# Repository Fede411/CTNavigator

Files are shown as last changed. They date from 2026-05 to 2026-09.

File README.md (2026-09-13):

# CTNavigator

An open-source surgical navigation prototype for orthopaedic oncological surgery, built entirely from low-cost consumer hardware and an open software stack. It localizes a surgical instrument with a stereo pair of Microsoft Kinect v1 sensors and displays it in real time within the patient's CT inside [3D Slicer](https://www.slicer.org/).

This repository contains the code and STL files developed for the Master's Thesis *"Design, Development and Validation of an Open-Source Orthopaedic Oncological Surgical Navigator"* (Universidad Politécnica de Madrid, ETSIT).

> **Status — research prototype.** This system is a proof of concept. Its accuracy (target registration error of ≈9.5 mm) is **not** sufficient for clinical use, and it carries no medical-device certification. It is intended as a reproducible research and development platform, not for use on patients.

---

## How it works

The system has two components that communicate over the [OpenIGTLink](http://openigtlink.org/) protocol:

1. **Tracking backend (C#)** — acquires infrared frames from two Kinect v1 cameras, detects the retroreflective spheres, reconstructs their 3D positions by stereo triangulation, estimates the pose of the tracked instrument and reference marker, and streams the resulting transforms.
2. **Navigation module (Python / 3D Slicer)** — receives those transforms, registers physical space to the CT via paired fiducials, and renders the instrument in real time inside the patient's anatomy.

```
Kinect A ─┐
          ├─► C# tracking backend ──(OpenIGTLink TRANSFORM)──► 3D Slicer module ──► navigation view
Kinect B ─┘
```

---

## Requirements

### Hardware
- **2× Microsoft Kinect v1 (Model 1414)**, mounted as a stereo rig (a 3D-printable casing is provided).
- Each Kinect on its **own USB controller** (two Kinect v1 units saturate a single controller's bandwidth).
- A retroreflective-marker instrument and a reference marker (STL files provided in [`/models`](models)).

### Software
- **Windows** (the Kinect v1 SDK is Windows-only).
- **Kinect for Windows SDK v1.8**.
- **.NET Framework** (matching the backend build).
- **3D Slicer 5.x** with the **SlicerIGT** and **SlicerOpenIGTLink** extensions installed.
- *(Optional, for calibration)* MATLAB with the Stereo Camera Calibrator app, or OpenCV.

---

## Installation

### 1. Tracking backend
A precompiled executable is provided in `/backend`. On first run it creates two folders next to the executable — `output/` (characterization and mapping CSVs) and `calib/` (calibration captures) — so no path configuration is required.

### 2. 3D Slicer module
The navigation module is a Python scripted module (`CTNavigator.py`, `CTNavigator.ui`).

1. In 3D Slicer, go to **Edit → Application Settings → Modules**.
2. Under **Additional module paths**, add the folder containing `CTNavigator.py`.
3. Restart Slicer. The module will appear under the **CTNavigator** category.

The module launches the tracking backend (`KinectTracker.exe`) automatically; keep it in the same folder as `CTNavigator.py`. To use a different location, set the `CTNAVIGATOR_EXE` environment variable to its full path.

---

## Calibration

Example calibration parameters are included so the system runs out of the box, **but calibrating your own rig is practically obligatory** — the extrinsics depend on the exact physical placement of your two cameras.

Two independent routes are supported:
- **MATLAB Stereo Camera Calibrator** (reference).
- **Two-stage OpenCV pipeline** (fully open-source alternative): each camera is calibrated individually over its full field of view, then the stereo extrinsics are solved with the intrinsics held fixed.

Place the resulting parameters in the calibration folder used by the backend (see the absolute-path note above). A 3D-printable checkerboard pattern is provided in [`/models`](models).

---

## Usage

1. Connect and power both Kinects (each on its own USB controller).
2. Run the tracking backend; confirm both cameras stream infrared and the markers are detected.
3. In 3D Slicer, open the **CTNavigator** module and load the patient CT (and segmented model, if available).
4. Open the OpenIGTLink connection to the backend; the connection status is shown in the module.
5. **Register**: click each anatomical landmark on the CT, then capture the same points physically with the instrument tip (one capture per landmark, same order). The fiducial registration error is displayed and colour-coded as feedback.
6. Navigate: the instrument now appears in real time within the patient's imaging. A dedicated navigation window can be opened for the clinical view.

---

## Repository structure

| Path | Contents |
|---|---|
| `SlicerModule/` | 3D Slicer Python module (`CTNavigator.py`, `CTNavigator.ui`, `Resources/`) and a copy of the tracking backend (`KinectTracker.exe`) |
| `KinectTracker/Kinect-PLUS/` | C# tracking backend source (`.cs`, `.csproj`, `packages.config`) |
| `Hardware/KinectCase/` | STL files for the stereo-camera casing and mounts |
| `Hardware/Calibration/` | Example checkerboard STL used for calibration |

> The `KinectTracker.exe` shipped alongside the module is the compiled backend; the C# sources under `KinectTracker/Kinect-PLUS/` build the same executable. NuGet packages (Emgu.CV, MathNet, etc.) are restored automatically on build.

---

## Known limitations

- **Not for clinical use.** Target registration error ≈9.5 mm, far above what orthopaedic oncological resection requires, and with no CE marking or regulatory approval.
- **Discontinued hardware.** The Kinect v1 is end-of-life and no longer manufactured; long-term reproducibility would benefit from migrating to a currently supported depth camera (e.g. Intel RealSense D455). The tracking pipeline is not tied to the Kinect — it only requires a calibrated stereo pair of infrared cameras.
- **Working volume and pose availability** depend on position and orientation; tracking degrades in peripheral and oblique regions.

---

## Citation

If you use this work, please cite the accompanying Master's Thesis:

> F. Sangineto Cotrina, *Design, Development and Validation of an Open-Source Orthopaedic Oncological Surgical Navigator*, Master's Thesis, Universidad Politécnica de Madrid (ETSIT), 2026.

---

## License

This project is released under the [BSD 3-Clause License](LICENSE). You are free to use, modify and redistribute it, including commercially, provided the copyright notice and disclaimer are retained and the authors' names are not used to endorse derived products without permission.

---

## Acknowledgements

Developed within the collaboration between the UPAM3D unit of *Hospital General Universitario Gregorio Marañón* and the Bioengineering and Telemedicine Group (GBT-UPM). Built on the open-source ecosystem of 3D Slicer, SlicerIGT and OpenIGTLink.

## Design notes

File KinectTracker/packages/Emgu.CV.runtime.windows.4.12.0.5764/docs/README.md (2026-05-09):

## About this package

This package is part of the 4.12.0 release of Emgu CV. 

For online documentation please visit
<https://www.emgu.com/wiki/files/4.12.0/document/index.html>

Release note can be found at
<https://www.emgu.com/wiki/index.php/Version_History#Emgu.CV-4.12.0>

## Note

If you are targeting .Net Framework, please read this first:
<https://www.emgu.com/wiki/index.php/Download_And_Installation#Targeting_.Net_Framework>

If you have issues getting the pacakge installed for your project, and your project use packages.config to manage nuget packages, the following instructions will help:
<https://www.emgu.com/wiki/index.php/Download_And_Installation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>

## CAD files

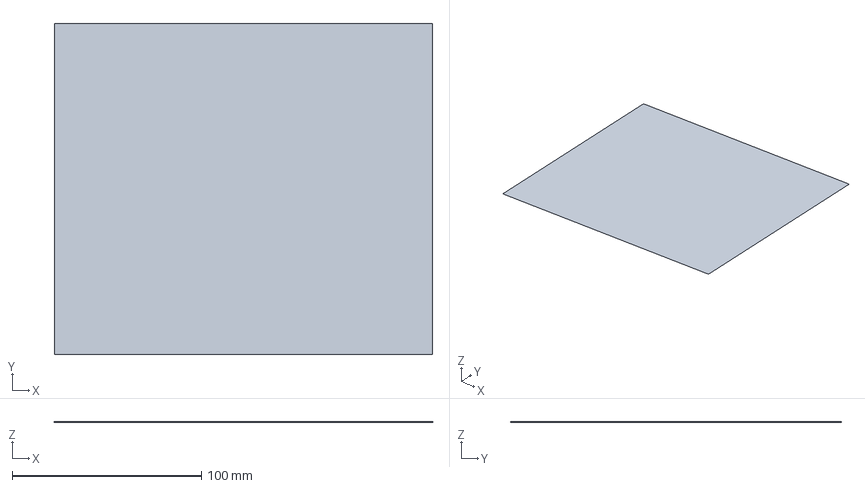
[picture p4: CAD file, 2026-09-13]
Hardware/Calibration/checkerboard_25mm_8x7.3mf
200.0 x 175.0 x 0.22 mm

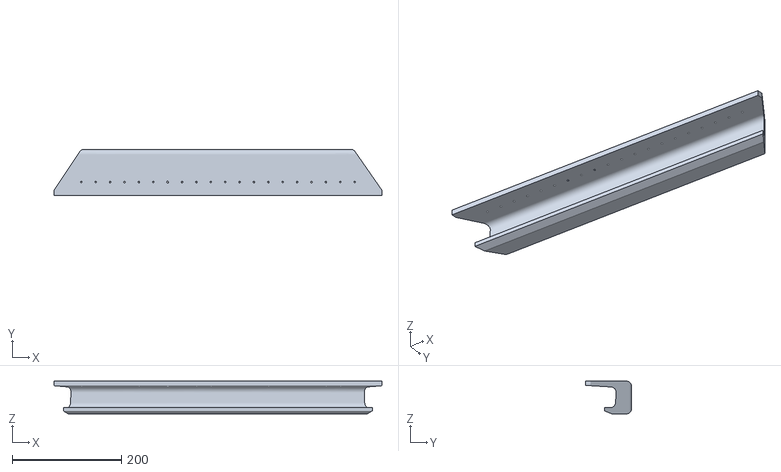
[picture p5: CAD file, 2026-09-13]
Hardware/KinectCase/KinectCase_M3.5.stl
600.0 x 85.0 x 60.0

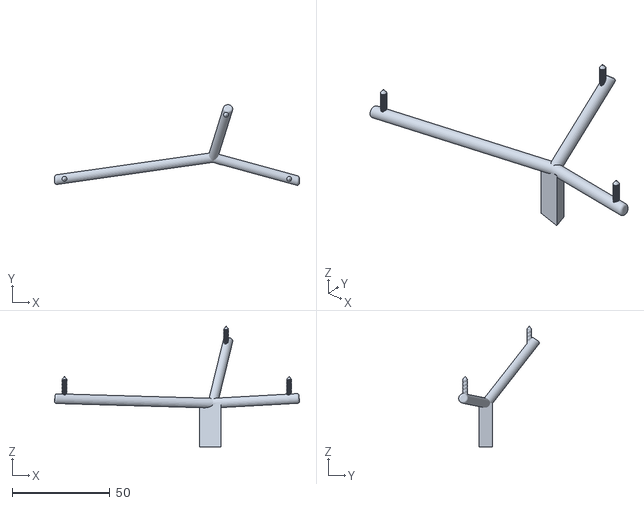
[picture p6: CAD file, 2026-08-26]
Hardware/marcadorV2.stl
125.4 x 41.3 x 61.9

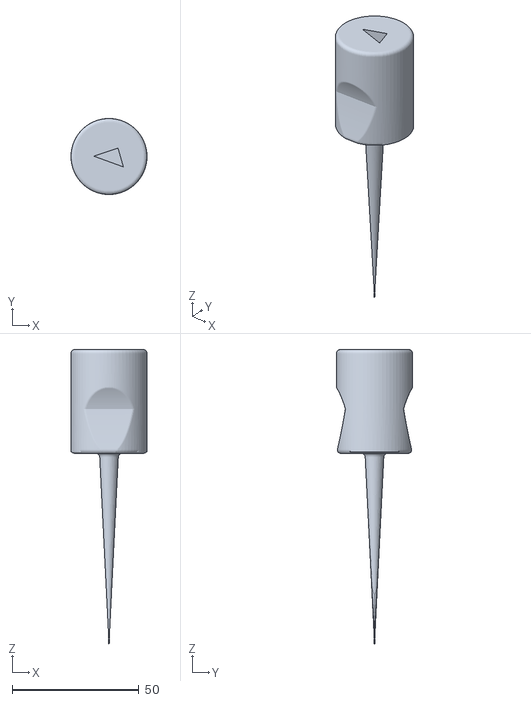
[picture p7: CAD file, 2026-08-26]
Hardware/instrumento3.stl
30.0 x 30.0 x 116.0

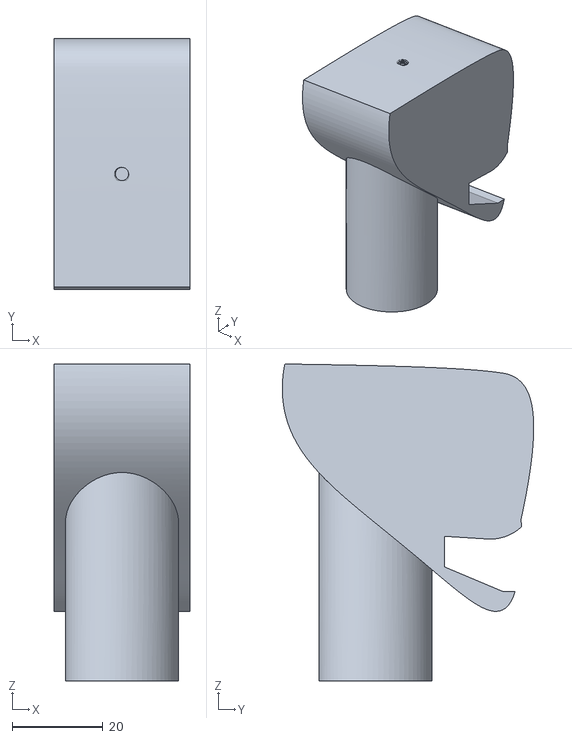
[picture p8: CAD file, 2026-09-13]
Hardware/KinectCase/adaptador_tripod_kinect_M6.stl
30.0 x 55.5 x 70.0

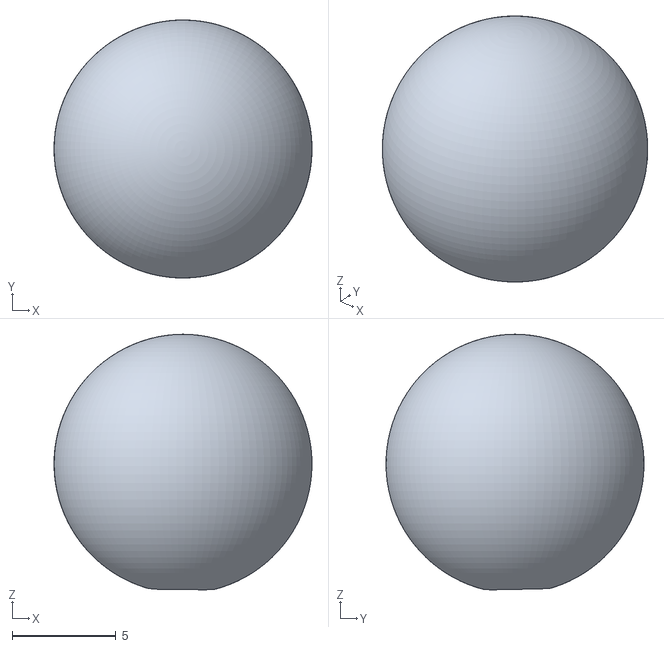
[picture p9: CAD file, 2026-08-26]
Hardware/BolaIR.stl
12.4 x 12.4 x 12.3

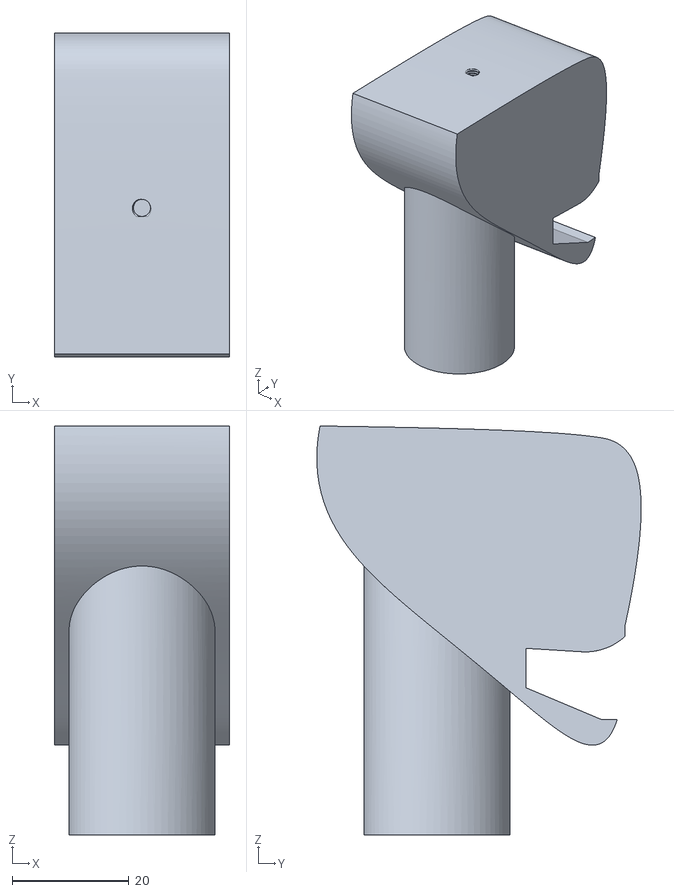
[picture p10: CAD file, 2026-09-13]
Hardware/KinectCase/adaptador_tripod_kinect_M8.stl
30.0 x 55.5 x 70.0

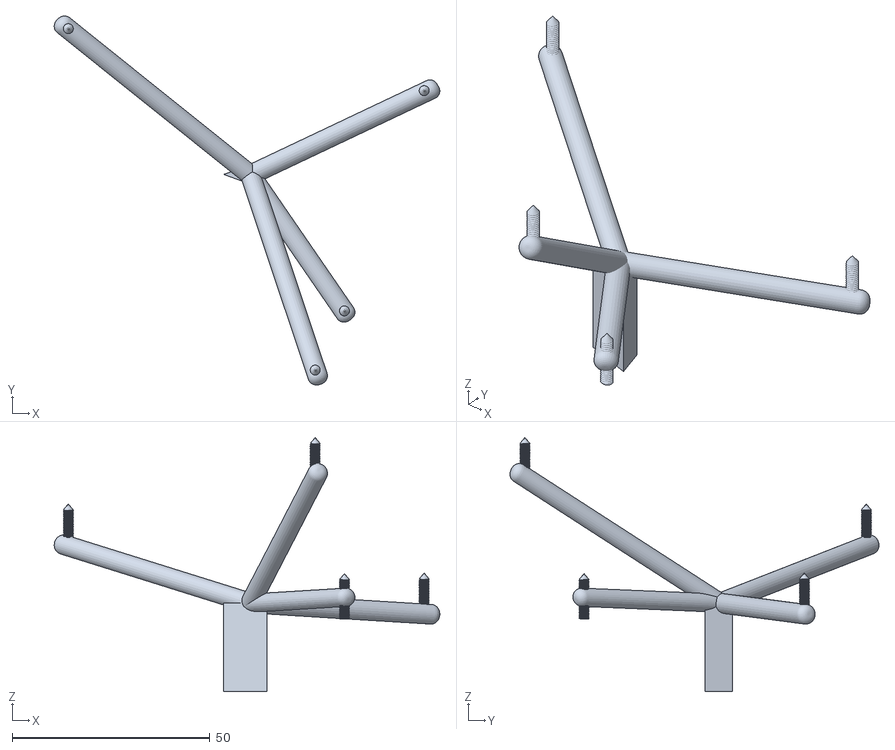
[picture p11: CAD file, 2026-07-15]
Hardware/corona_esferas_instrumentoV2.stl
97.6 x 93.4 x 64.3

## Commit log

2026-04-20 Add main module and reference marker model
    [marcadorIR.stl]
2026-05-09 Organize structure and Kinect Tracker Proof of Concept
    [marcadorIR.stl]
2026-05-09 3D Tracking from 800-1500mm added
2026-05-13 Slicer module can output separate CT Window, new 3D models
    [instrumentoIR.stl, marcadorIR.stl]
2026-05-18 Added working model geometries, matchers, pose estimation and implementing kalman filter
2026-06-17 Fixed Slicer bug, IR detection model changed, balls are tracked via a dynamic contour
    [ErroresInstrumentales(Recuperado automáticamente).xlsx, marcadorIR.stl, marcadorV3.stl]
2026-06-30 STEREO SETUP: New functions and arquitecture, better continuous tracking
    [ErroresInstrumentales(Recuperado automáticamente).xlsx]
2026-07-06 Slightly optimized stereo tracking params, all executables controllable via Slicer, added visible instrument
    [corona_esferas_instrumento.stl, instrumento2.stl]
2026-07-15 Tracking filters + best-hypothesis matcher, acquisition audio, UI to .ui
    [corona_esferas_instrumentoV2.stl]
2026-08-26 Finalized tracking and visualization, Slicer module registration averaged jitter for minimized registration errors
    [BolaIR.stl, corona_esferas_instrumentoV3.stl, encaje_escaleno.stl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]
2026-09-13 Remove old STL versions from Hardware
    [corona_esferas_instrumento.stl, corona_esferas_instrumentoV2.stl, encaje_escaleno.stl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]
2026-09-13 Added auxiliary stls to Hardware
    [KinectCase_M3.5.stl, adaptador_tripod_kinect_M6.stl, adaptador_tripod_kinect_M8.stl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]
2026-09-19 Removed wrong model version
    [corona_esferas_instrumentoV3.stl]
2026-09-19 Corrected sphere crown STL version
    [corona_esferas_instrumentoV2.stl]
